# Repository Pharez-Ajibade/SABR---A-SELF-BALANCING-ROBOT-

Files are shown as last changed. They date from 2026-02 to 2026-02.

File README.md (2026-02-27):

# SABR — Self-Balancing Robot



### A LIGIENCE Project

SABR is a self-balancing robot built entirely from scratch using core engineering principles, control theory, and continuous iteration. This is not a copy of a tutorial — every design decision was made from the ground up using physics, math, and a lot of trial and error.

This repo contains all project files across multiple build versions,including a stepper motor version, DC motor version, and servo motor version.

---

## 📌 Project Description

SABR is modelled after an **inverted pendulum on a cart** — one of the most classic unstable systems in control theory. The robot uses an IMU to measure its tilt angle, feeds that into a PID control loop, and drives its motors to correct its position in real time at approximately 200Hz.

The goal of this project was to explore:
- Real-world control theory and system modelling
- Sensor fusion for accurate angle estimation
- Motor dynamics and actuator selection
- PCB design and embedded systems development

---

## Development Roadmap

### Phase 1 — Research & Physics
- Studied the inverted pendulum system model
- Derived equations of motion using torque, inertia, and angular acceleration
- Researched closed-loop control systems best suited for the build
- Key insight: longer rod = slower fall (inertia scales with L², torque scales with L)

### Phase 2 — Component Selection & Breadboard Prototyping
- Selected ESP32 as the microcontroller for dual-core capability and 240MHz clock speed
- Selected MPU6050 for IMU (3-axis accelerometer + gyroscope)
- Implemented and tested Complementary Filter and Kalman Filter for sensor fusion
- Tested stepper motor control with TMC2208 drivers using dual-core threading on ESP32
- Plotted and compared gyro drift, accelerometer noise, and filter outputs via serial oscilloscope

### Phase 3 — SABR V1 (Stepper Motor Version)
- 3D modelled and printed frame inspired by Aaed Musa's Impulse robot
- DIY rubber band wheels for grip
- Hand-soldered circuit board
- **Result:** Motors skipped steps, insufficient torque, thermal shutdown of drivers
- **Lesson:** Always calculate required torque before selecting motors

### Phase 4 — SABR V2 (Simplified Stepper Version)
- Redesigned to a shorter, simpler frame to reduce torque requirements
- Same circuit board, revised code
- **Result:** Closer to balancing but still inconsistent — heavy oscillations, drifting

### Phase 5 — PCB Design & New Motor Iterations
- Designed first custom PCB using KiCad, manufactured by PCBWay
- Switched to geared DC motors with TB6612FNG then L298N motor driver
- **Issue:** PWM dead zone (0–40%) meant motors didn't respond to small PID corrections
- Switched to 20kg·cm continuous rotation servos
- **Issue:** Too slow compared to high-end servos used in reference builds
- **Lesson:** Actuator speed and response time are just as critical as control theory

### Phase 6 — The Breakthrough
- Discovered the root cause of all balancing failures: **lack of friction**
- DIY wheels had insufficient grip on hard surfaces (table, tile floor)
- Robot successfully balanced on carpet
- Revised Kalman filter tuning: increased gyro trust from ~75% to over 95%
- Result: Significantly smoother angle readings and robot response

### Phase 7 — Tuning & Final Version
- Tuned PID starting with Kp, then Kd for dampening, then Ki for steady-state error
- Tested cascaded PI controllers (angular + position)
- Tested dynamic microstepping (1/16 step under 0.5° error)
- Tested variable Kp at different error angles
- Final implementation: Angular PID controller with gyro-based D term
- **Result:** SABR balances stably — position/velocity controller pending for V2

---

## 🧰 Components List

### Microcontroller
| Component | Details |
|---|---|
| ESP32 Dev Module | 240MHz dual-core, Wi-Fi + Bluetooth |

### IMU / Sensors
| Component | Details |
|---|---|
| MPU6050 | 3-axis accelerometer + 3-axis gyroscope |

### Motors & Drivers — Final Version
| Component | Details |
|---|---|
| NEMA 17 Stepper Motors (x2) | Primary drive motors |
| TMC2208 Stepper Drivers (x2) | Silent driver with StealthChop, 1/8 microstepping |

> ⚠️ **Other motor iterations tested:** Geared DC motors (with TB6612FNG and L298N drivers) and 20kg·cm continuous rotation servos were both tested in earlier versions. Both were ultimately limited by dead zones and speed respectively. See the video for the full breakdown.

### Power
| Component | Details |
|---|---|
| LiPo Battery | Main power source |
| Buck Converter | Steps down battery voltage for electronics |

### Mechanical
| Component | Details |
|---|---|
| 3D Printed Frame | Custom designed, multiple versions |
| DIY Rubber Band Wheels | Custom modelled with grooves for rubber bands |
| M3 Hardware | Screws and standoffs for assembly |

### PCB
| Component | Details |
|---|---|
| Custom PCB (KiCad) | Designed and manufactured via PCBWay |
| JST Connectors | Power input connectors |
| THT Components | Through-hole components throughout |

---

## 📐 Torque Calculation — Motor Sizing Guide

Before selecting your motors, calculate the torque required to balance your robot. Skipping this step is the single biggest mistake you can make — and yes, this was learned the hard way.

### Formula

```
τ = m · g · L · sin(θ)
```

| Variable | Description |
|---|---|
| `τ` | Required torque (N·m) |
| `m` | Total mass of the robot (kg) |
| `g` | Gravitational acceleration (9.81 m/s²) |
| `L` | Distance from wheel axle to robot's centre of gravity (m) |
| `θ` | Maximum tilt angle the robot must recover from (degrees) |

### How to Apply It

1. Estimate `L` as the height from the motor axle to the top of your robot — this is a deliberate overestimate and that's fine
2. Set `θ` to at least **30°** as your minimum recovery angle
3. Calculate `τ`, then **multiply by 1.5× to 2×** as a safety margin — never run at minimum spec
4. Use this value to shortlist motors, then cross-check stall torque vs rated speed at your operating voltage

### Critical Nuances

> **Torque scales with L, but inertia scales with L²**
> A longer robot falls more slowly (easier to catch) but demands significantly more torque to correct. The two don't cancel out — inertia always wins at extreme lengths.

> **Height vs Speed tradeoff**
> A shorter robot requires less torque but falls much faster, demanding higher motor speeds and faster control loop response. A longer robot is more forgiving on speed but punishing on torque.

> **Motor dead zones kill small corrections**
> For DC motors especially, any PWM range where the motor doesn't move (typically 0–40%) creates a dead zone. When the PID output is small (near balance), the motors simply won't respond — and the robot falls. This cannot be tuned away. It is a hardware problem.

> **Stepper motor thermal limits**
> Steppers draw near-full current even at standstill. Under aggressive PID correction, drivers will heat up fast and can thermal-shutdown mid-balance. Size your drivers and cooling accordingly.

> **You cannot out-tune a hardware deficiency**
> Increasing Kp to compensate for insufficient torque only causes jitter and oscillation. If the motor can't physically move fast enough or with enough force to catch the robot, no controller gain will fix it.

---

## 🖼️ Visuals

### Circuit Diagram
Circuit Diagram

DESIGN OVER VIEW

> *Full schematic including ESP32, MPU6050, TMC2208 drivers, buck converter and power connections*

---

### PCB Design
PCB Layout

kiCAD PCB SCHEMATIC SCREENSHOT

kiCAD PCB 3D SCREENSHOT 2

kiCAD PCB 3D SCREENSHOT

> *KiCad PCB layout — front and back copper layers with ground and 5V infill*

---

### 3D Model & Assembly
3D Model

SABR TEST PLATFORM 3d model
SABR TEST PLATFORM

https://github.com/user-attachments/assets/52e14db4-9bfc-43c8-931d-ffd89795920e
> *SABR frame — full 3D model with motor mounts, wheel design and electronics bay*

<!-- Optional: Replace with an animated GIF of the 3D model rotating -->
<!-- ![3D Model Animation](images/3d_model_animation.gif) -->

---

### Software & Tools
- **Arduino IDE / PlatformIO** — for ESP32 firmware
- **KiCad** — PCB design
- **Fusion 360 / CAD software** — 3D frame modelling
- **Serial Oscilloscope** — for sensor and filter output visualisation

### Key Concepts
- **Inverted Pendulum Model** — system dynamics and equations of motion
- **Sensor Fusion** — Complementary Filter and Kalman Filter for stable angle estimation
- **PID Control** — Proportional, Integral, Derivative tuning for real-time balance
- **Dual-Core Threading (ESP32)** — separating step pulse timing from control loop calculations
- **Microstepping** — smoother stepper motor motion using 1/8 and 1/16 step modes

### Control Loop
- Sampling rate: ~200Hz
- IMU → Kalman Filter → Error Calculation → PID → Motor Output → Repeat
- D term based on gyroscope measurement (not error delta) for reduced jitter
- Gyro trust ratio: >95% in Kalman filter for smooth response

### Known Issues & Future Improvements (V2)
- [ ] Implement position/velocity controller to eliminate drift
- [ ] Proper silicone wheels for reliable grip on all surfaces
- [ ] Add power switch to PCB in next revision
- [ ] Explore bipedal walking version (BIPEDAL SABR)
- [ ] External wheel encoders for closed-loop position control
- [ ] Use of BLDC AND foc FOR MAIN TYRES 

---

## 🙏 Credits & References
- Inspired by Aaed Musa's Impulse Robot
- PCB manufactured by [PCBWay](https://www.pcbway.com)
- Mathematical references and resources linked in video description
- https://ctms.engin.umich.edu/CTMS/?example=InvertedPendulum&section=SystemModeling
- SENSOR FUSION
   -   https://youtu.be/7HVPjkWOrLE?si=l8aKTfFblnUTjnXL
   -   https://youtu.be/hQUkiC5o0JI?si=4qGIxBiCNVThZBNw
   -   https://youtu.be/RZd6XDx5VXo?si=hTg3l8ioiw1hPVCZ
- Accelerometer Roll and Pitch ; https://mwrona.com/posts/accel-roll-pitch/

---

*Part of the LIGIENCE robotics series — building real robots from first principles.*

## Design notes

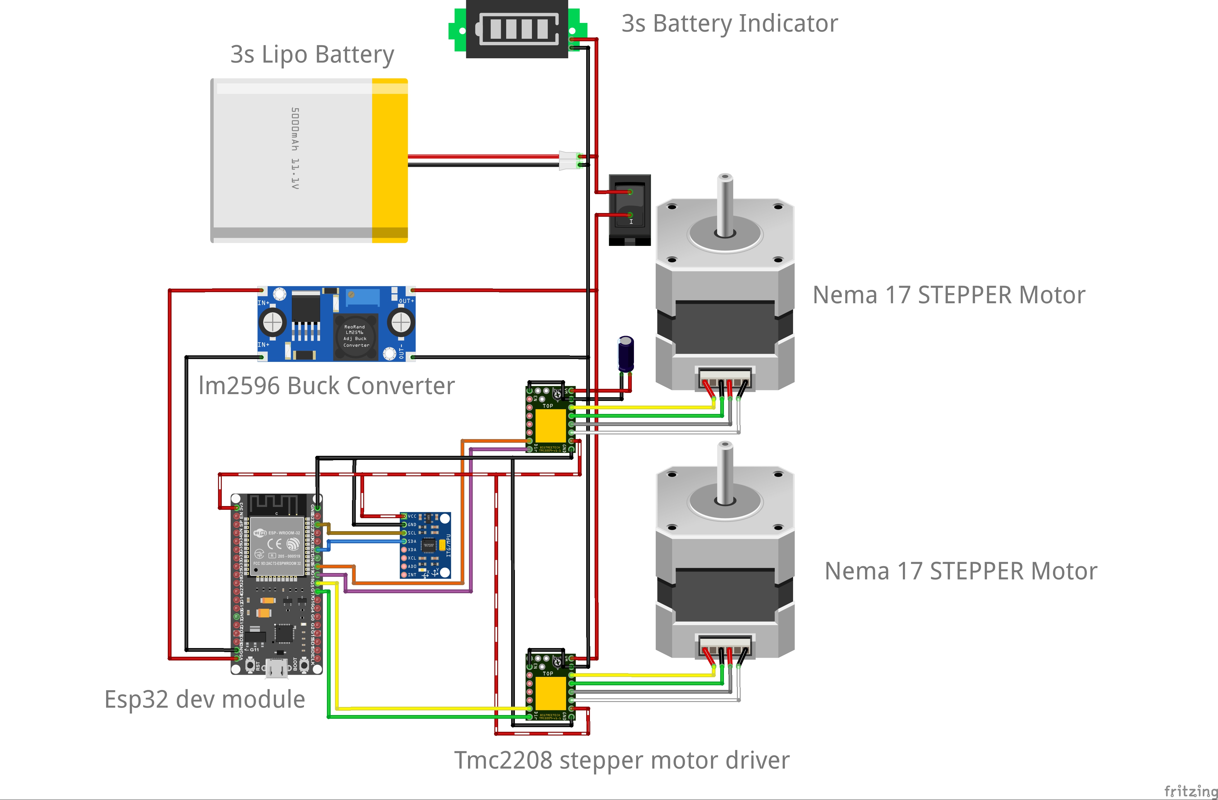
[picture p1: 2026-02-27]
DESIGN OVER VIEW.jpg

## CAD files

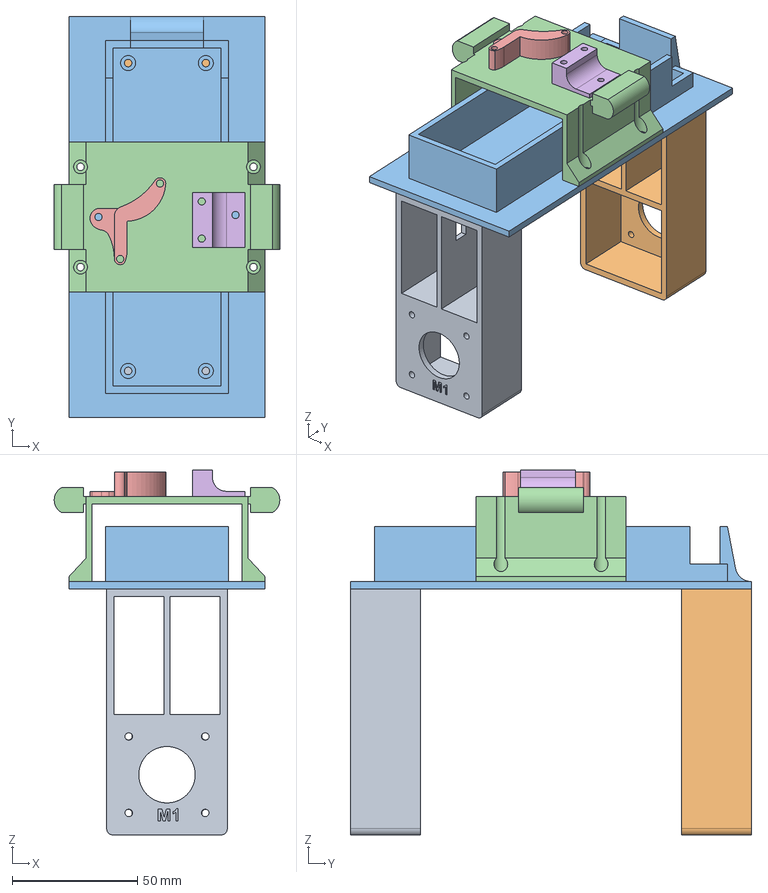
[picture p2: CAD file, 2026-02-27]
SABR 3D MODEL SSTEP FILE/SABR TEST PLATFORM.step
90.0 x 160.0 x 145.6 mm
M1 MOUNT
M2 MOUNT
Battery Mount
Circuit Mount
lm2596 mount
mpu6050 mount

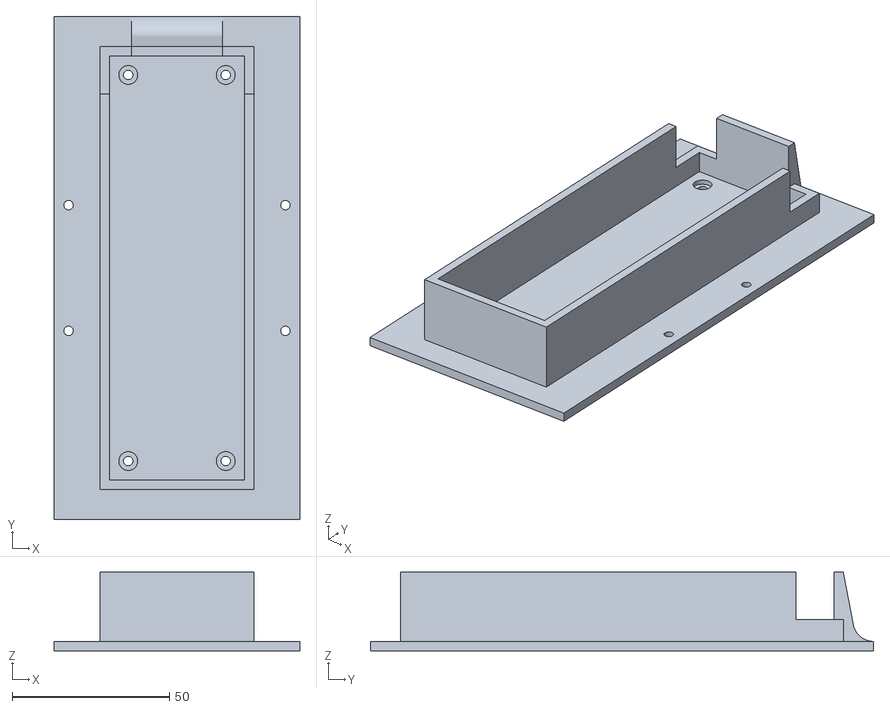
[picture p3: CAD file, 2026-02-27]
SABR 3D MODEL STL PRINT FILES/Battery Mount.stl
78.1 x 160.0 x 25.0

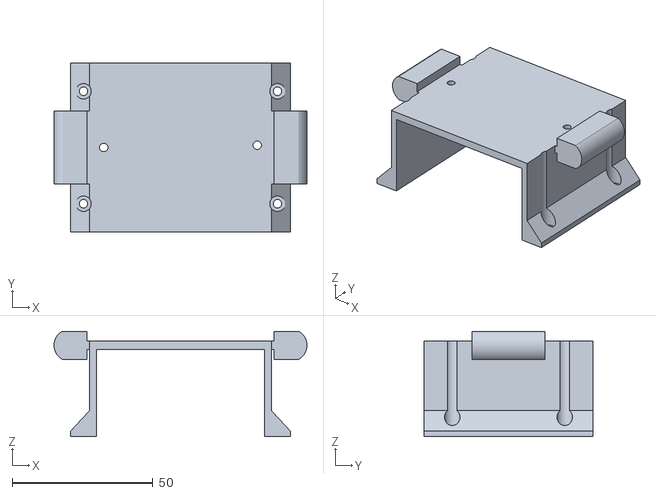
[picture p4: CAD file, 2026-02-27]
SABR 3D MODEL STL PRINT FILES/Circuit Mount.stl
90.0 x 60.0 x 37.5

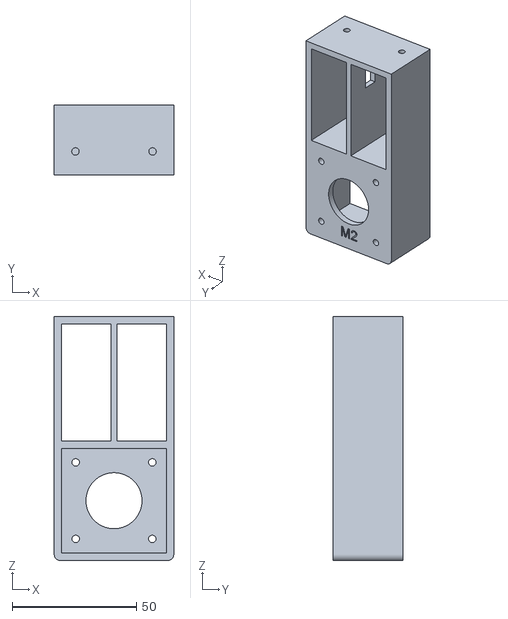
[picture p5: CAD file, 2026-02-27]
SABR 3D MODEL STL PRINT FILES/M2 Mount .stl
48.1 x 28.0 x 98.1

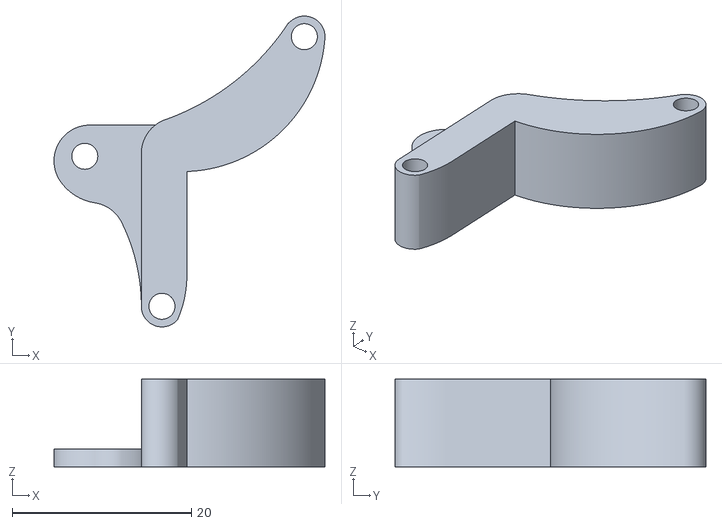
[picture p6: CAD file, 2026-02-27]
SABR 3D MODEL STL PRINT FILES/LM2596 Mounr.stl
30.3 x 34.7 x 9.80

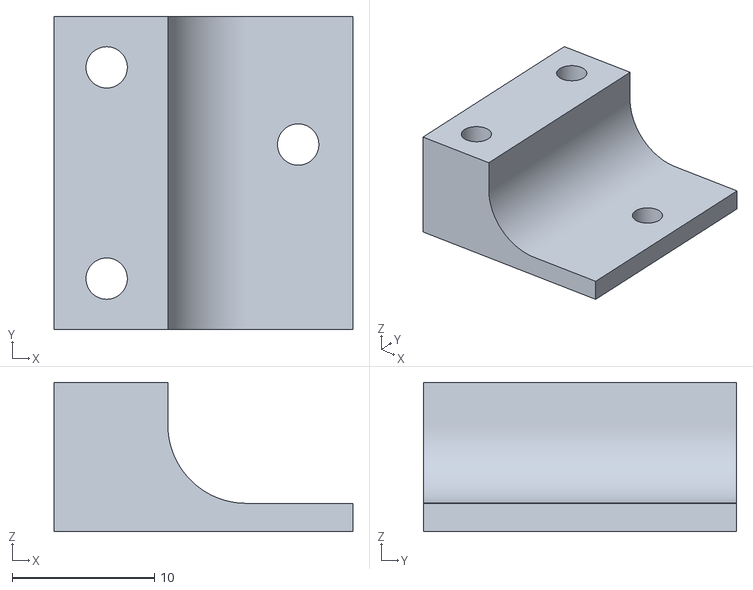
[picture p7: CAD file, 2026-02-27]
SABR 3D MODEL STL PRINT FILES/MPU6050 Mount.stl
21.0 x 22.0 x 10.5

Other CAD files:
SABR 3D MODEL STL PRINT FILES/M1 Mount .stl

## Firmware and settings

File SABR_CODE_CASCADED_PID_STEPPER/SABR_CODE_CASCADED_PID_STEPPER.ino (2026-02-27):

// PLE3ASE UNDERSTAND I WRITE COMMENTS MY OWN WAY, BUT NONETHELESSTHE BUILD VIDEO FOR THIS IS ON YOUTUBE @ LIGIENCE 
// Link; https://youtu.be/h8H8bgWLwpI

#include <Wire.h>
float Gyro_Roll, Gyro_Pitch, Gyro_Yaw;
//       p         q          r
float AccX, AccY, AccZ;
//      x     y     z 
float Acc_Roll, Acc_Pitch;

float sampling_rate = 0.004f; // sampling rate is seconds - 0.005 seconds which is = 200Hz 
unsigned long sampling_rate_timer = 4000; //  timer microseconds
unsigned long SR_current_timer;
unsigned long SR_last_timer;

// ---------------------MPU6050 ACCELEROMETER AND GYRO TRADINGS TO ROLL AND PITCH------------------

void Accel_gyro_signals(void) {
  Wire.beginTransmission(0x68);
  Wire.write(0x1A);
  Wire.write(0x05);
  Wire.endTransmission();
  Wire.beginTransmission(0x68);
  Wire.write(0x1C);
  Wire.write(0x10);
  Wire.endTransmission();
  Wire.beginTransmission(0x68);
  Wire.write(0x3B);
  Wire.endTransmission(); 
  Wire.requestFrom(0x68,6);
  int16_t AccXLSB = Wire.read() << 8 | Wire.read(); // raw counts sensitivity of +- 8g
  int16_t AccYLSB = Wire.read() << 8 | Wire.read();
  int16_t AccZLSB = Wire.read() << 8 | Wire.read();
  Wire.beginTransmission(0x68);
  Wire.write(0x1B); 
  Wire.write(0x8);
  Wire.endTransmission();                                                   
  Wire.beginTransmission(0x68);
  Wire.write(0x43);
  Wire.endTransmission();
  Wire.requestFrom(0x68,6);
  int16_t GyroX=Wire.read()<<8 | Wire.read();
  int16_t GyroY=Wire.read()<<8 | Wire.read();
  int16_t GyroZ=Wire.read()<<8 | Wire.read();

  Gyro_Roll=(float)GyroX/65.5 + 1.40; // to degrees/s then minus to calibrate to 0 
  Gyro_Pitch=(float)GyroY/65.5 - 4.13;
  Gyro_Yaw=(float)GyroZ/65.5 + 0.78;

// ---------------Accelerometer direct values to acceleration in g, calibration offfset and then to pitch and roll 

  AccX=(float)AccXLSB/4096.0f - 0.02f; // acceleration in g - minus is for manual calibration from readingd when at rest , can be converted to m/s and g would then = 9.81
  AccY=(float)AccYLSB/4096.0f - 0.05f; 
  AccZ=(float)AccZLSB/4096.0f - 0.029f;
  
   // Always normalize, just prevent division by zero
  float acc_magnitude = sqrt(AccX*AccX + AccY*AccY + AccZ*AccZ);

  if (acc_magnitude > 0.1f) {
   AccX /= acc_magnitude;
   AccY /= acc_magnitude;
   AccZ /= acc_magnitude;
   }

   Acc_Pitch = atan2f(-AccX, sqrt(AccY*AccY + AccZ*AccZ)) * RAD_TO_DEG; // Value in Radians --Convert to Degrees -- sqrt(AccX² + AccY² + AccZ²) ≈ 1 g If acceleration is in g then use 1.o as "g" in any calculations but if it is in m/s2 use 9.81
   Acc_Roll = atan2f(AccY, AccZ) * RAD_TO_DEG; // Value in Radians --Convert to Degrees 
    // RAD TO DEGREE  = (180.0f / 3.14159f )
}



//-------------------Kalman filter variables-----------------------------------
// Kalman filter for roll and pitch
float KalmanAngleRoll = 0.0f;              // Filtered roll angle
float KalmanUncertaintyRoll = 2.0f * 2.0f; // Initial uncertainty

float KalmanAnglePitch = 0.0f;              // Filtered pitch angle
float KalmanUncertaintyPitch = 2.0f * 2.0f; // Initial uncertainty

// Process and measurement noise (tune these)
const float Q_angle = 0.003f; // process noise - how much you trust the gyro - higher value means higher noise = lesss trust 
const float R_angle = 0.05f;  // measurement noise - how much you trust the accelerometer - higher value means higher noise = lesss trust 


//-------------------Kalman filter function -----------------------------------

void Kalman_1d(float &KalmanState, float &KalmanUncertainty, float KalmanInput, float KalmanMeasurement) {
    // 1. Prediction (gyro integration)
    KalmanState += KalmanInput * sampling_rate;           // gyro * sampling_rate
    KalmanUncertainty += Q_angle * sampling_rate;        // uncertainty grows

    // 2. Compute Kalman gain
    float KalmanGain = KalmanUncertainty / (KalmanUncertainty + R_angle);

    // 3. Update state with measurement (accelerometer)
    KalmanState += KalmanGain * (KalmanMeasurement - KalmanState);

    // 4. Update uncertainty
    KalmanUncertainty = (1.0f - KalmanGain) * KalmanUncertainty;
}

//------------------------------CONTROL MODES ----------------------

uint8_t control_mode = 1;  // 0 = angle only, 1 = angle + position

//------------------------------MOTOR POSITION TRACKING ----------------------

// Position tracking (in motor steps)
volatile int32_t motor_left_steps = 0;    // volatile because accessed in interrupt
volatile int32_t motor_right_steps = 0;   // volatile because accessed in interrupt
int32_t position_avg = 0;                 // Average position of both motors

// Control mode 0: Angle only (your original system)
// Control mode 1: Angle + Position (new cascaded system)

//------------------------------ ANGLE PID  ----------------------

float angle_setpoint = 3.0f;  // Renamed from 'setpoint' - this will be DYNAMIC now!
float angle_error = 0.0f;

float KP_angle = 280.0f;  // Renamed from KP
float Ki_angle = 20.0;    // Renamed from Ki  
float Kd_angle = 2.5;    // Renamed from Kd

float Integral_angle = 0.0F;     // Renamed from Integral
float Integral_angle_max = 500.0f;

// Derivative filter
float Derivative_angle = 0.0f;

float angle_error_previous = 0.0f;

float PID_angle_output = 0.0F;   // Renamed from PID_output


//------------------------------POSITION PID (NEW!) ----------------------

float position_setpoint = 0.0f;  // Target position (0 = stay where we started)
float position_error = 0.0f;

float KP_pos = 1.5f;     // Position P gain - START CONSERVATIVE
float Ki_pos = 0.0f;     // Position I gain - START WITH ZERO
float Kd_pos = 0.0f;     // Position D gain - helps damping

float Integral_pos = 0.0f;
float Integral_pos_max = 35.0f;  // Limit position integral (degrees)

float Derivative_pos = 0.0f;
float position_prev = 0;

float position_error_previous = 0.0f;

float PID_pos_output = 0.0f;  // This feeds into angle_setpoint!

#define PID_POS_MAX 35.0f  // Maximum angle setpoint from position control

float POSITION_DEADZONE = 0.5f;

//------------------------------ANGLE PID FUNCTION ----------------------

void angle_PID() {

    angle_error = angle_setpoint - KalmanAnglePitch;

    // -------- PROPORTIONAL --------
    float P = KP_angle * angle_error;

    // -------- INTEGRAL (ANTI-WINDUP) --------
    if (fabsf(angle_error) < 8.0f && fabsf(PID_angle_output) < 500.0f) {
        Integral_angle += angle_error * sampling_rate;
        Integral_angle = constrain(Integral_angle, -Integral_angle_max, Integral_angle_max);
    }
    else {
        Integral_angle = 0.0f;  // ← ADDED: Reset when conditions not met
    }

    float I = Ki_angle * Integral_angle;

    // -------- DERIVATIVE ---------

   // Derivative_angle = (angle_error - angle_error_previous) / sampling_rate ;

   // angle_error_previous = angle_error;

   // float D = Kd_angle * Derivative_angle;

    float D = -Kd_angle * Gyro_Pitch;

    // -------- OUTPUT--------
    PID_angle_output = P + I + D;
}

//------------------------------POSITION PID FUNCTION ----------------------

void position_PID() {
    // Calculate position error (convert steps to normalized value)
     position_error = (position_setpoint - position_avg) / 1000.0f;

    float P = KP_pos * position_error;

    Integral_pos += position_error * sampling_rate;
    Integral_pos = constrain(Integral_pos, -Integral_pos_max, Integral_pos_max);
    
    // Reset if very far
    if (fabsf(position_error) > 2.0f) {
        Integral_pos = 0.0f;
    }

    float I = Ki_pos * Integral_pos;

    // In position_PID():
    float pos_rate = (float)(position_avg - position_prev) / sampling_rate;
    //                ← Cast to float
    position_prev = position_avg;

    float D = -Kd_pos * (pos_rate / 1000.0f);

    PID_pos_output = P + I + D;

    PID_pos_output = constrain( PID_pos_output,-PID_POS_MAX, PID_POS_MAX);
}


//------------------------------MotorFUNCTION ----------------------

//-----------------------------MOTOR ESSENTIAL DATA 
// steps per revolution for my nema 17 is 200 at 1.8degrees per step 
// using the microstep of 1/16th gives 32000 steps per revolution
// Currently set to 1/8th step on a 200 steps per revolution 
float p ;

int steps_per_rev = 1600; // 1/8th step on a 200 steps per revolution 

//---------------------------- stepper motor 1 
const int DIR = 18;
const int STEP = 19;
const int MS1_M1 = 16;
const int MS2_M1 = 4;

//----------------------------stepper motor 2 

const int DIR2 = 17;
const int STEP2 = 5;
const int MS1_M2 = 0;
const int MS2_M2 = 2;

unsigned long stepper_motor_us_pulse ;

unsigned long M_Current_timer ;
unsigned long M_Last_timer ;

//------------------------------DYNAMIC MICROSTEPPING ----------------------

uint8_t microStep = 8;           // Start at 1/4 step (less vibration)
uint8_t lastMicroStep = 8;

//------------------------------SET MICROSTEPPING FUNCTION (CORRECTED) ----------------------

void setMicroStep(uint8_t uStep) {
    switch(uStep) {
        case 2:  // Half step (1/2) - HIGH torque
            digitalWrite(MS1_M1, LOW);
            digitalWrite(MS2_M1, HIGH);
            digitalWrite(MS1_M2, LOW);
            digitalWrite(MS2_M2, HIGH);
            steps_per_rev = 400;
            break;
            
        case 4:  // Quarter step (1/4) - Good balance
            digitalWrite(MS1_M1, HIGH);
            digitalWrite(MS2_M1, LOW);
            digitalWrite(MS1_M2, HIGH);
            digitalWrite(MS2_M2, LOW);
            steps_per_rev = 800;
            break;
            
        case 8:  // Eighth step (1/8) - DEFAULT, smooth
            digitalWrite(MS1_M1, LOW);
            digitalWrite(MS2_M1, LOW);
            digitalWrite(MS1_M2, LOW);
            digitalWrite(MS2_M2, LOW);
            steps_per_rev = 1600;
            break;
            
        case 16:  // 1/16 step - Smoothest (with internal interpolation)
            digitalWrite(MS1_M1, HIGH);
            digitalWrite(MS2_M1, HIGH);
            digitalWrite(MS1_M2, HIGH);
            digitalWrite(MS2_M2, HIGH);
            steps_per_rev = 3200;
            break;
            
        default:  // Fallback to 1/8 (most common default)
            digitalWrite(MS1_M1, LOW);
            digitalWrite(MS2_M1, LOW);
            digitalWrite(MS1_M2, LOW);
            digitalWrite(MS2_M2, LOW);
            steps_per_rev = 1600;
            uStep = 8;
            break;
    }
    
    microStep = uStep;
    
   //Serial.print("Microstepping: 1/");
   //Serial.println(microStep);
   //Serial.print(" = ");
   //Serial.print(steps_per_rev);
   //Serial.println(" steps/rev");
}

// -------MultiCore Processing--------------
TaskHandle_t Task1;
TaskHandle_t Task2;

void setup() {
  // Serial initiialisation
  Serial.begin(115200);
  // I2C Initialisation
  Wire.setClock(400000);
  Wire.begin();
  delay(250);
  Wire.beginTransmission(0x68); 
  Wire.write(0x6B);
  Wire.write(0x00);
  Wire.endTransmission();
  

  pinMode(STEP, OUTPUT);
  pinMode(DIR, OUTPUT);
  pinMode(MS1_M1 , OUTPUT);
  pinMode(MS2_M1 , OUTPUT);

  
  pinMode(STEP2, OUTPUT);
  pinMode(DIR2, OUTPUT);
  pinMode(MS1_M2, OUTPUT);
  pinMode(MS2_M2, OUTPUT);

  setMicroStep(8);
  control_mode = 1;

  delay(250);

  M_Last_timer = micros(); 
  SR_last_timer = micros();

  //create a task that will be executed in the Task1code() function, with priority 1 and executed on core 0
  xTaskCreatePinnedToCore(
                    Task1code,   /* Task function. */
                    "Task1",     /* name of task. */
                    10000,       /* Stack size of task */
                    NULL,        /* parameter of the task */
                    1,           /* priority of the task */
                    &Task1,      /* Task handle to keep track of created task */
                    0);          /* pin task to core 0 */                  
  delay(500); 

  xTaskCreatePinnedToCore(
                    Task2code,   /* Task function. */
                    "Task2",     /* name of task. */
                    10000,       /* Stack size of task */
                    NULL,        /* parameter of the task */
                    1,           /* priority of the task */
                    &Task2,      /* Task handle to keep track of created task */
                    1);          /* pin task to core 1 */
    delay(500); 

}

  // CALCULATION TASKS RUNNING ON CORE 0 

  void Task1code( void * pvParameters ){

  Serial.print("Task1 running on core ");
  Serial.println(xPortGetCoreID());

  for(;;){
   
   SR_current_timer = micros();
   if (SR_current_timer - SR_last_timer >= sampling_rate_timer ){

    Accel_gyro_signals();
    
    // Apply Kalman filter
   //Kalman_1d(KalmanAngleRoll, KalmanUncertaintyRoll, Gyro_Roll, Acc_Roll);
   Kalman_1d(KalmanAnglePitch, KalmanUncertaintyPitch, Gyro_Pitch, Acc_Pitch);

   //Serial.print("Kalman Roll: "); Serial.println(KalmanAngleRoll, 2);
   Serial.print("Kalman_Pitch:"); Serial.println(KalmanAnglePitch, 2);
   
   // Average position from both motors (in steps)
   position_avg = (motor_left_steps + motor_right_steps) / 2;

   //Serial.print(" Pos:");
   //Serial.print(position_avg);
   //Serial.print(" L:");
   //Serial.print(motor_left_steps);
   //Serial.print(" R:");
   //Serial.println(motor_right_steps);

// ===== CASCADED CONTROL =====
    
    if (control_mode == 0) {
        // Mode 0: Angle only (original behavior)
        angle_setpoint = 3.0f;
        angle_PID();
        
    } else if (control_mode == 1) {
        // Mode 1: Position + Angle (cascaded)
        position_PID();                    // Outer loop: calculate desired angle
        angle_setpoint = PID_pos_output + 2.0f ;  // Add your C.G. offset
        angle_PID();                       // Inner loop: achieve that angle
    }

// Convert PID output to motor speed (same as before)
    p = fabsf(PID_angle_output);  // Changed from PID_output
    //Serial.print("PID_ANGLE_OUTPUT: ");   Serial.println(PID_angle_output);  
    p = constrain(p, 0.001f, 40000.0f);
    
// ======== DYNAMIC MICROSTEPPING ==========
   setMicroStep(8);
   // lastMicroStep = microStep;

   // if (microStep == 16) {
      // Currently at 1/16 → Switch to 1/8 if tilting
   //   if (fabsf(angle_error) > 1.0f) {
   //    microStep = 8;
   //   }
   // }
   // else if (microStep == 8) {
      // Currently at 1/8 → Only switch back to 1/16 (NO 1/4 step!)
   //  if (fabsf(angle_error) < 0.5f) {
   //   microStep = 16;
   //   }
   // }

   // if (microStep != lastMicroStep) { setMicroStep(microStep); }

// ======== DIRECTION CONTROL ==========    
    if (PID_angle_output > 0) {  // Changed from PID_output
        digitalWrite(DIR, LOW);
        digitalWrite(DIR2, HIGH);
        stepper_motor_us_pulse = (unsigned long)(1000000.0f/p);
    }
    else if(PID_angle_output < 0) {  // Changed from PID_output
        digitalWrite(DIR, HIGH);
        digitalWrite(DIR2, LOW);
        stepper_motor_us_pulse = (unsigned long)(1000000.0f/p);
    }
  
    // Fall detection (same as before)
   if (fabsf(angle_error) < 0.3f) {
    stepper_motor_us_pulse = 100000UL;
    }

    if (fabsf(angle_error) > 45.0f) {  // Changed from error
        stepper_motor_us_pulse = 100000UL;
    }
    //Serial.print("stepper_motor_us_pulse: ");
    //Serial.println(stepper_motor_us_pulse);

    SR_last_timer = SR_current_timer;
    }

   } 

  }



  void Task2code( void * pvParameters ){
  Serial.print("Task1 running on core ");
  Serial.println(xPortGetCoreID());

  for(;;){
    
    M_Current_timer = micros();
    if (M_Current_timer - M_Last_timer >= stepper_motor_us_pulse){
     
     digitalWrite(STEP, HIGH);
     digitalWrite(STEP2, HIGH);
     delayMicroseconds(1);        // 1–2 µs pulse width
     digitalWrite(STEP, LOW);
     digitalWrite(STEP2, LOW);

     
  //    ORRRRRRRR........
  //    digitalWrite(STEP, !digitalRead(STEP));
  //   digitalWrite(STEP2, !digitalRead(STEP2));


    // Check direction and increment/decrement step counters
     
     // Motor 1 (left)
     if (digitalRead(DIR) == LOW) {
       motor_left_steps++;   // Moving forward
     } else {
       motor_left_steps--;   // Moving backward
     }
     
     // Motor 2 (right)
     if (digitalRead(DIR2) == HIGH) {
       motor_right_steps++;  // Moving forward
     } else {
       motor_right_steps--;  // Moving backward
     }

    M_Last_timer = M_Current_timer;

    }

  } 
  }



  void loop() {                         }
